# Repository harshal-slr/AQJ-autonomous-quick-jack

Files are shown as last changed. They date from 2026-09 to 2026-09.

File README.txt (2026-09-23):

===============================================================
 AUTONOMOUS QUICK JACK (AQJ)
 Digital Modeling of Interactive Systems and Interfaces (DMISI)
 Universita degli Studi di Napoli Federico II (UniNa)
===============================================================

OVERVIEW
--------
The Autonomous Quick Jack (AQJ) is an automated vehicle-lifting device
that positions itself under a selected wheel and raises the vehicle with
minimal human intervention, aimed at faster and safer tire changes and
undercarriage inspections than a traditional jack stand.

This repository contains the project files: the SolidWorks CAD model,
a MATLAB / Simscape Multibody physics simulation, structural load-case
studies, and supporting documentation.

NOTE: All files are uploaded individually (flat), not in folders. Before
using the CAD or MATLAB model, download the files and place the related
ones together in a single folder on your computer so their internal
references resolve correctly (see HOW TO USE below).

REQUIREMENTS
------------
- SolidWorks (to open .SLDPRT parts, .SLDASM assemblies, .SLDDRW drawings)
  * SolidWorks Simulation add-in to open the .CWR study result files
- MATLAB / Simulink with Simscape and Simscape Multibody
  (developed with the Simscape Multibody Contact Forces Library v24.2.x,
   i.e. MATLAB R2024b or newer)
- A viewer for .STEP / .STL if you only need the neutral CAD geometry

FILES IN THIS REPOSITORY
------------------------
SolidWorks CAD (keep these together in one folder after download):
  - Autonomous Quick Jack.SLDASM   MAIN top-level assembly (open this first)
  - Body Assembly.SLDASM           body/frame sub-assembly
  - LM- Assembly_Final.SLDASM      linear-motion / lifting mechanism assembly
  - LM- Assembly_Final-CASE 1..4.CWR   SolidWorks Simulation load cases
  - Individual parts: Base Plate, Car_Base, body panels, AQJ_Wheel,
    Gearmotor, NEMA 17 motor, shafts, spacers, brackets, fasteners (.SLDPRT)
  - Gearmotor.STEP / nema 17.stp   neutral CAD geometry for other tools

MATLAB / Simscape Multibody simulation:
  - Contact_Forces_Library.prj     MATLAB project file (open this first)
  - aqj_one.slx                    main Simscape Multibody model
  - scenario_one.mat               simulation scenario / parameters
  - aqj_matlab_model.png           model screenshot
  - Simscape Multibody Contact Forces Library (v24.2.5.2)  required dependency

Documentation and results:
  - Autonomous Quick Jack.pdf / .SLDDRW   engineering drawing
  - LM- Assembly_Final-CASE *.docx / .LOG  simulation reports and logs
  - Autonomous Quick Jack.docx     project proposal
  - PW8_Autonomous Quick Jack.pptx  presentation
  - Project image renders (.png / .jpg)

HOW TO USE
----------
0. DOWNLOAD FIRST
   - GitHub's web preview cannot open SolidWorks or MATLAB files.
   - Download the files you need and group the related ones into a single
     folder locally so cross-references (assemblies, model paths) resolve.

1. VIEW THE CAD MODEL
   - Put all .SLDPRT, .SLDASM and .SLDDRW files in the same folder.
   - Open  Autonomous Quick Jack.SLDASM  in SolidWorks.
   - If any part is reported missing, point SolidWorks to the folder that
     contains the downloaded parts.
   - No SolidWorks? Use the .STEP / .STL files for geometry only.

2. REVIEW THE STRUCTURAL ANALYSIS
   - With the SolidWorks Simulation add-in enabled, open
     LM- Assembly_Final.SLDASM and load the CASE 1..4 (.CWR) studies.
   - Matching reports/logs are the LM- Assembly_Final-CASE *.docx follow the steps to perform load cases.

3. RUN THE PHYSICS SIMULATION
   - Keep the MATLAB files and the Contact Forces Library together in one folder.
   - Open MATLAB (R2024b or newer) with Simscape Multibody installed.
   - Open  Contact_Forces_Library.prj  (loads paths and dependencies),
     then open and run  aqj_one.slx.
   - scenario_one.mat holds the scenario parameters loaded by the model.

4. READ THE DOCUMENTATION
   - Start with the drawing PDF and the project image renders, then the
     proposal .docx and the presentation .pptx.

NOTES
-----
- SolidWorks assemblies only open correctly when every referenced part is
  in the same local folder.
- The MATLAB model depends on the Contact Forces Library; keep it in the
  same folder as the project file after download.

AUTHORS
-------
Harshal Rajesh Kokitkar
Shwetali Vitthal Bhuingade
Master's in Autonomous Vehicle Engineering, UniNa

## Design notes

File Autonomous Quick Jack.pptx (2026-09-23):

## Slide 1

DIGITAL MODELING OF INTERACTIVE SYSTEMS AND INTERFACES

AUTONOMOUS QUICK JACK

Group Members - 1. Shwetali Vitthal Bhuingade
2. Harshal Rajesh Kokitkar

University Of Naples Federico II.
Master's Degree In Autonomous Vehicle Engineering
Department Of Industrial Engineering

Project Guide’s: Prof. Patalano Stanislao.
Prof. Vitolo Ferdinando.

## Introduction

The Autonomous Quick Jack is a type of self-operating, movable lifting system created for vehicle maintenance, repairs, and other tasks that require lifting a vehicle more efficiently and user-oriented. It includes autonomous or semi-autonomous technology, which can lift and lower a vehicle with minimal human involvement, because it relies on electric or hydraulic systems.
Tire punctures are a common inconvenience that can disrupt daily routines. Traditional jack stands can be time-consuming to set up, especially in emergency situations. To address this issue, we propose the development of an Autonomous Quick Jack (AQJ). This innovative device aims to streamline the tire-changing process by autonomously positioning itself under the vehicle according to the selected wheel and lifting it with minimal human intervention.

## Project Objectives

The primary objectives of this project are:
● Autonomous Positioning: Develop a system that accurately identifies the input given by the user and positions the AQJ beneath it.
● Precise Lifting: Implement a mechanism to safely and efficiently lift the vehicle to the desired height given by the user.
● User-Friendly Interface: Design an intuitive user interface to control the AQJ and monitor its operations.
● Robust and Reliable: Ensure the AQJ is durable and can withstand various environmental conditions and usage scenarios.

## State of the Art

- Analytic Approach Model of an Automated Car Jack
- A method to Improve the Stability of Scissor Lifting Platform by using Finite Element Analysis
- Design, Manufacturing & Analysis of Hydraulic Scissor Lift

## Starting Status

A jack is an essential tool used for lifting a vehicle, particularly when changing a tire or performing maintenance that requires access underneath the car.
- Types of Jacks
There are three main types of jacks commonly used for vehicles:
1. Trolley Jack: This type features wheels for easy maneuverability and is suitable for lifting heavier vehicles. It provides stability and ease of use.
2. Bottle Jack: Compact and portable, bottle jacks are ideal for tight spaces but require a stable surface to operate effectively.
3. Scissor Jack: Typically found in many vehicles as part of the tire repair kit, scissor jacks are lightweight and operate by a cranking mechanism, making them suitable for emergency situations.

## 3D Modelling (SolidWorks)

Modelling Approach
During the design and development of new products, designers and engineers rely on both a bottom-up and top-down approach.
For modeling the AQJ, we employed a bottom-up approach. We began by designing the lifting mechanism (LM), and based on its overall dimensions, we subsequently designed the other components to fit accordingly. We utilized the sheet metal feature in SolidWorks to create the model.

## AQJ Isometric View

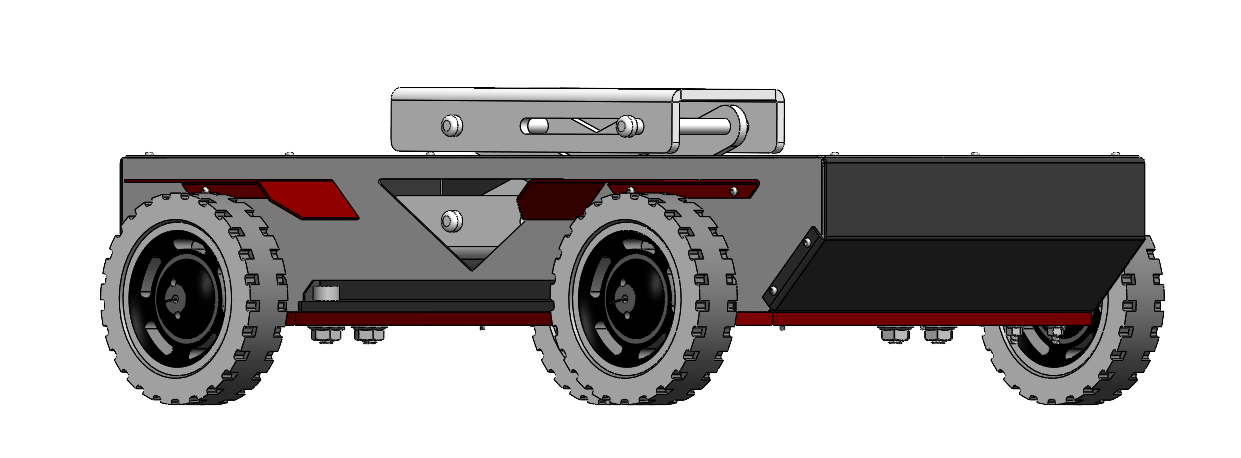
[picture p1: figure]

## Dimensions

For most vehicles, ground clearance typically ranges from 100 mm to 200 mm. Specifically, standard passenger cars often have a ground clearance around 130 mm, while sports cars may have lower clearances, sometimes as low as 110 mm, to enhance aerodynamics and handling.
The designed AQJ has a lifting range from 0-57mm.

## AQJ Static Condition Height Measurement (117.19 mm)

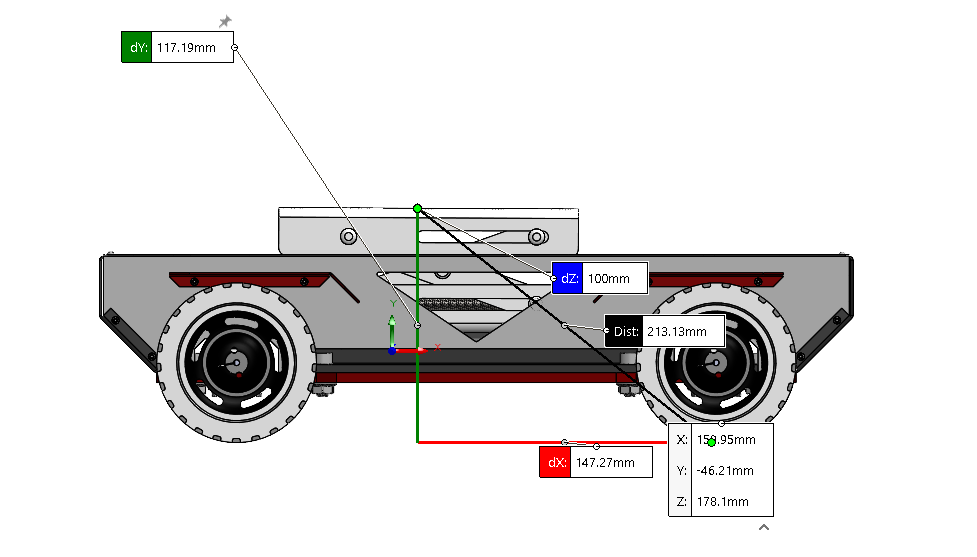
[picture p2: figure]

## AQJ Lifting Condition Height Measurement (175.01 mm)

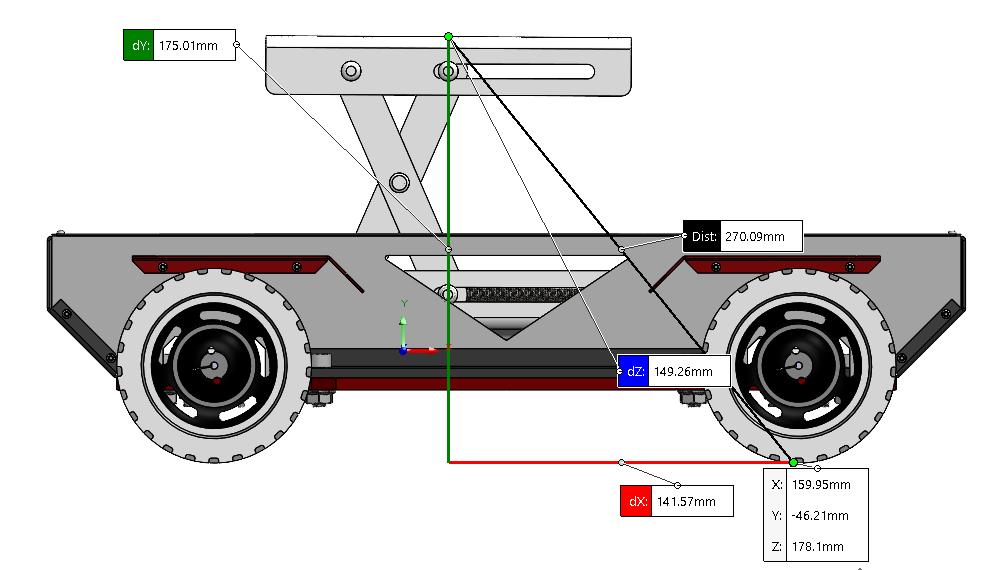
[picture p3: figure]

## AQJ Wheelbase Measurement (240 mm)

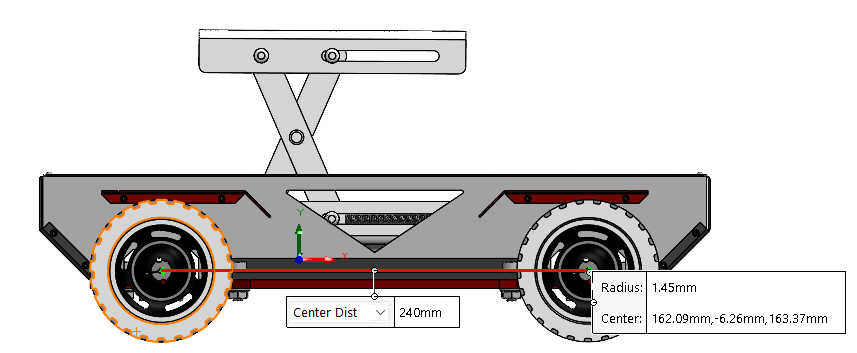
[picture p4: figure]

## AQJ Track Width Measurement (228 mm)

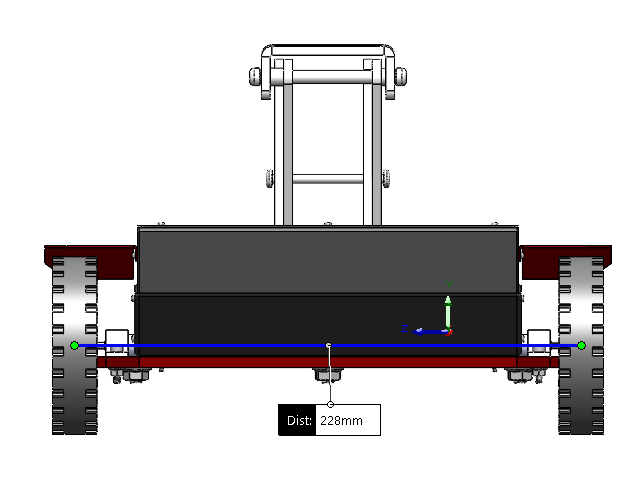
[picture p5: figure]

## Finite Element Analysis (SolidWorks)

Definition of analysis
The load acting on each wheel of a passenger car, the weight supported by a single wheel of a passenger vehicle depends on the vehicle's total weight and its weight distribution. Small autos usually weigh around 1,134 Kg and large automobiles about 1,950 Kg. Taking an average of small and large vehicles (1,134 + 1,950 = 3,084/2 = 1,542 Kg)
Assuming a 50/50 weight distribution, each wheel would support about 25% of the vehicle's total weight. Therefore, the weight on a single wheel can be calculated as follows:
Weight per wheel in kilograms: 1,542 kg × 0.25 = 385.5 kg
Weight per wheel in newtons: 385.5 kg × 9.81 m/s² ≈ 3,782 N
This calculation indicates that each wheel supports approximately 3,782 newtons.

## Analysis Case 1

Pre Processing
Defining geometry

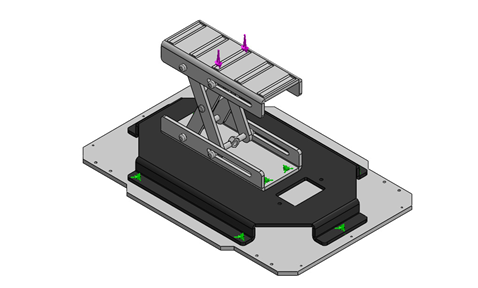
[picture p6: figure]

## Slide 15

Assigning Material Properties
The material used for the lifting mechanism is mild-steel for all the parts in the model.

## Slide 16

Applying Loads

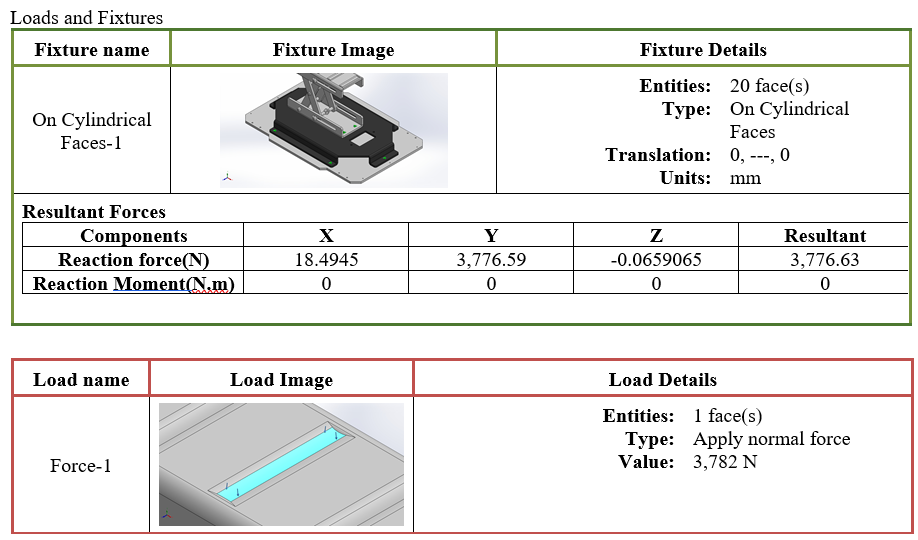
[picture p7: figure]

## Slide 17

Mesh

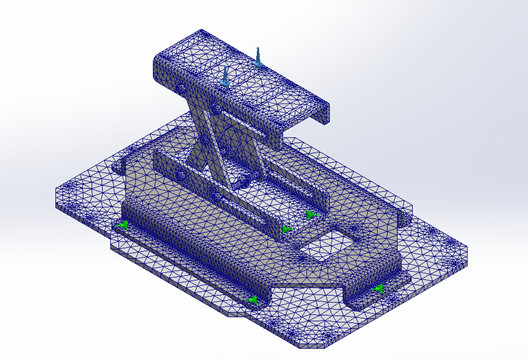
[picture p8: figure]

## Post Processing

Results
Case 1 Stress

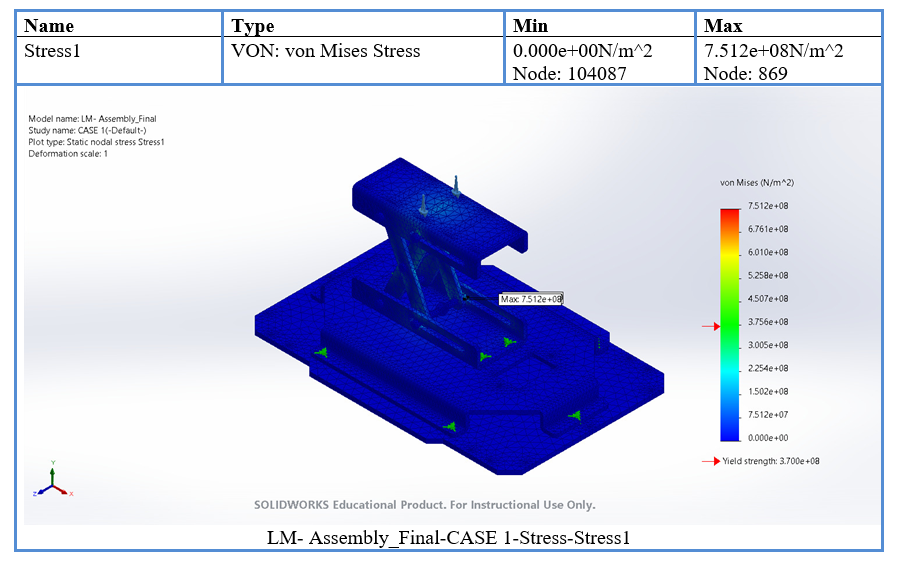
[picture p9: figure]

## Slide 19

Case 1 Displacement

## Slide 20

Case 1 Strain

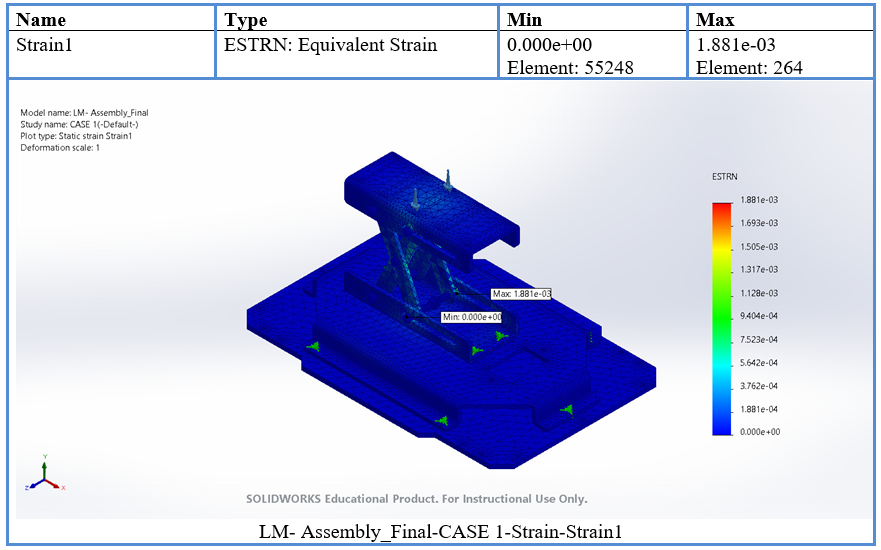
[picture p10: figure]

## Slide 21

Case 1 FOS

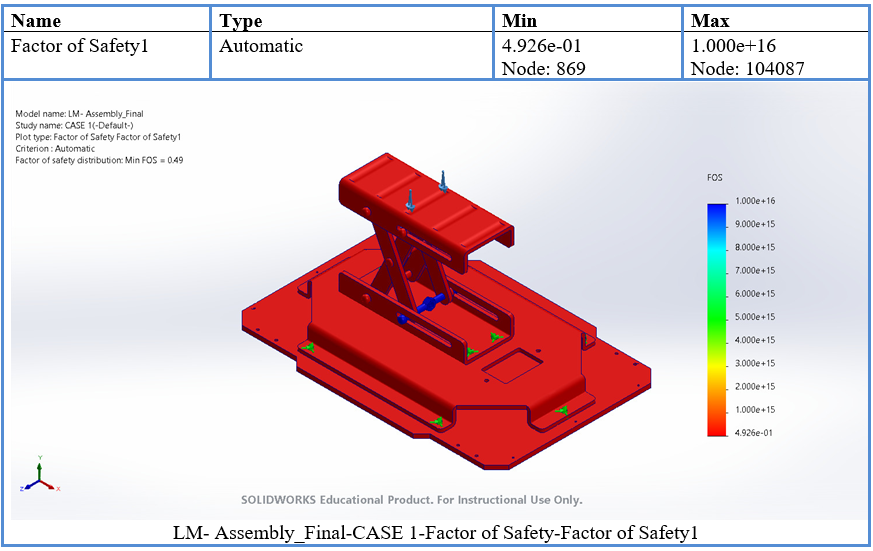
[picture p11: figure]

## Analysis Case 2

Pre Processing
Defining geometry

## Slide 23

Applying Loads

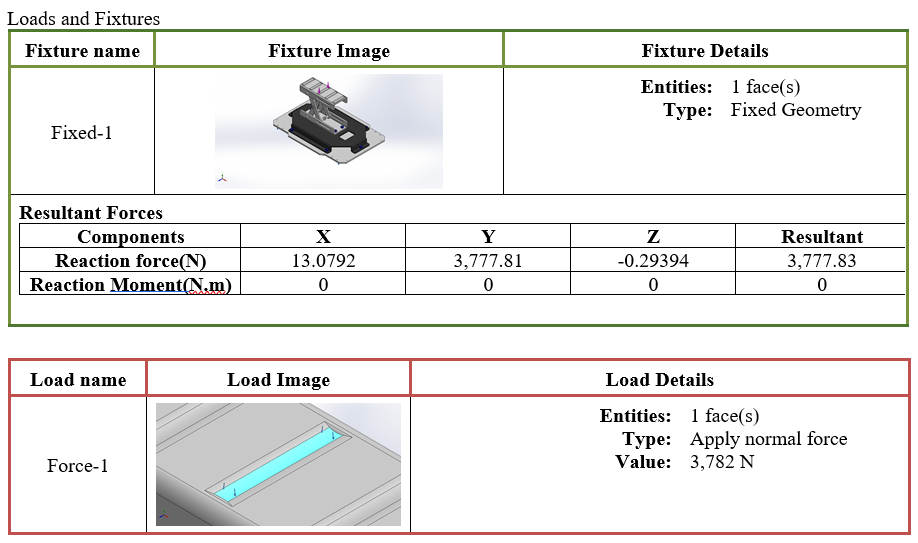
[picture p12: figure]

For Case 2 the applying fixtures on the cylindrical surface is replaced by Nut
and Bolt connection.

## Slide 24

Mesh

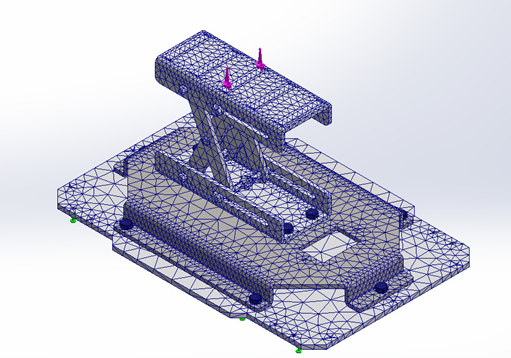
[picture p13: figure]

## Post Processing

Results
Case 2 Stress

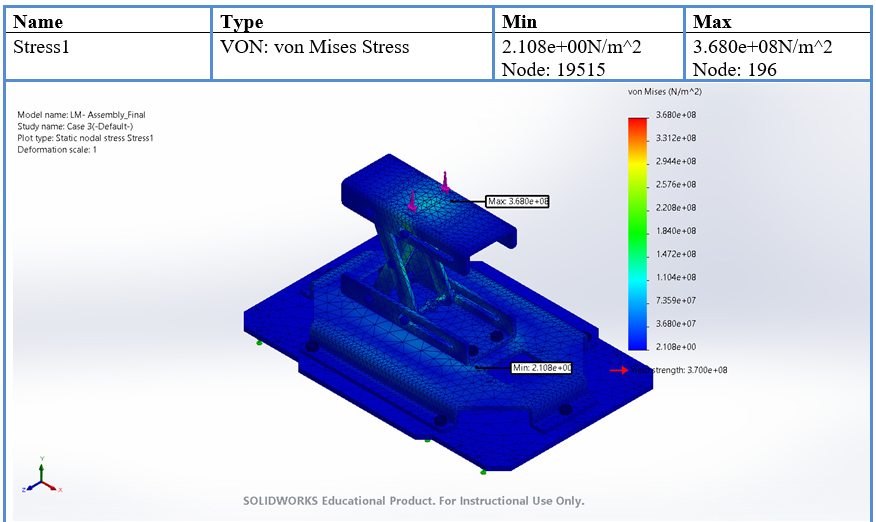
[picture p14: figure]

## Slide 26

Case 2 Displacement

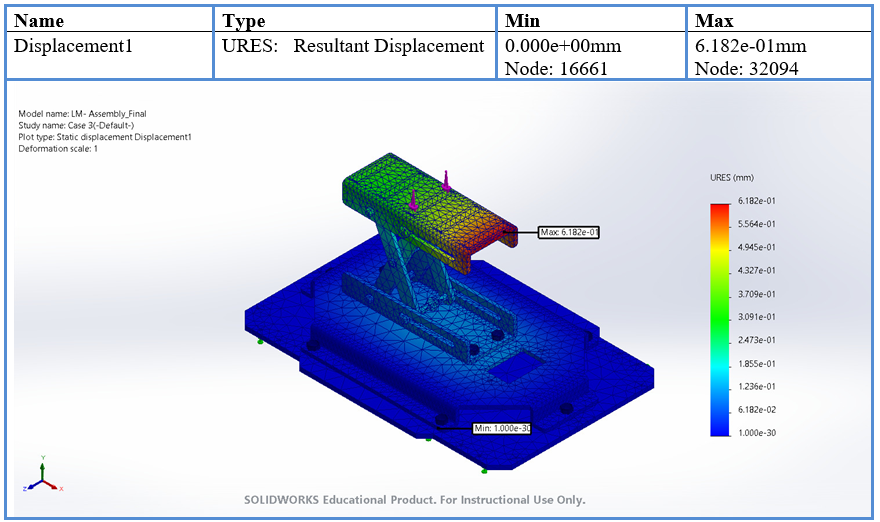
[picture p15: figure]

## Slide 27

Case 2 Strain

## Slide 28

Case 2 FOS

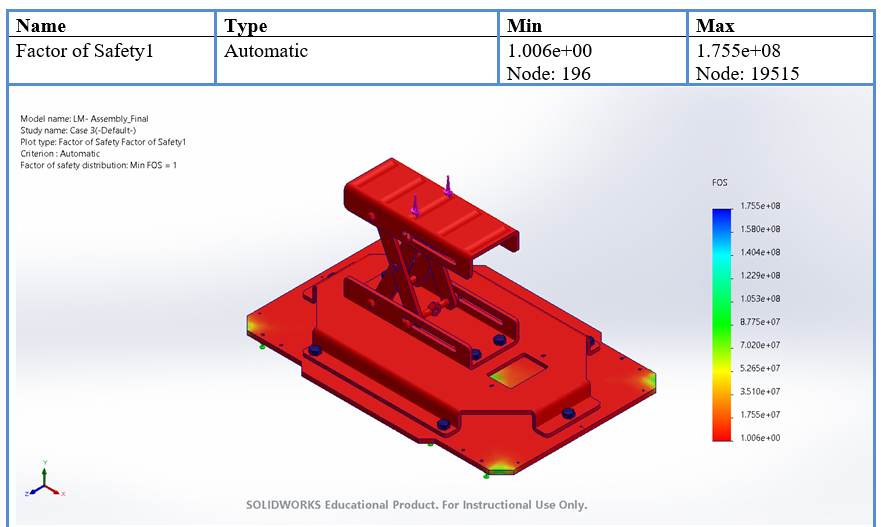
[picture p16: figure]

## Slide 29

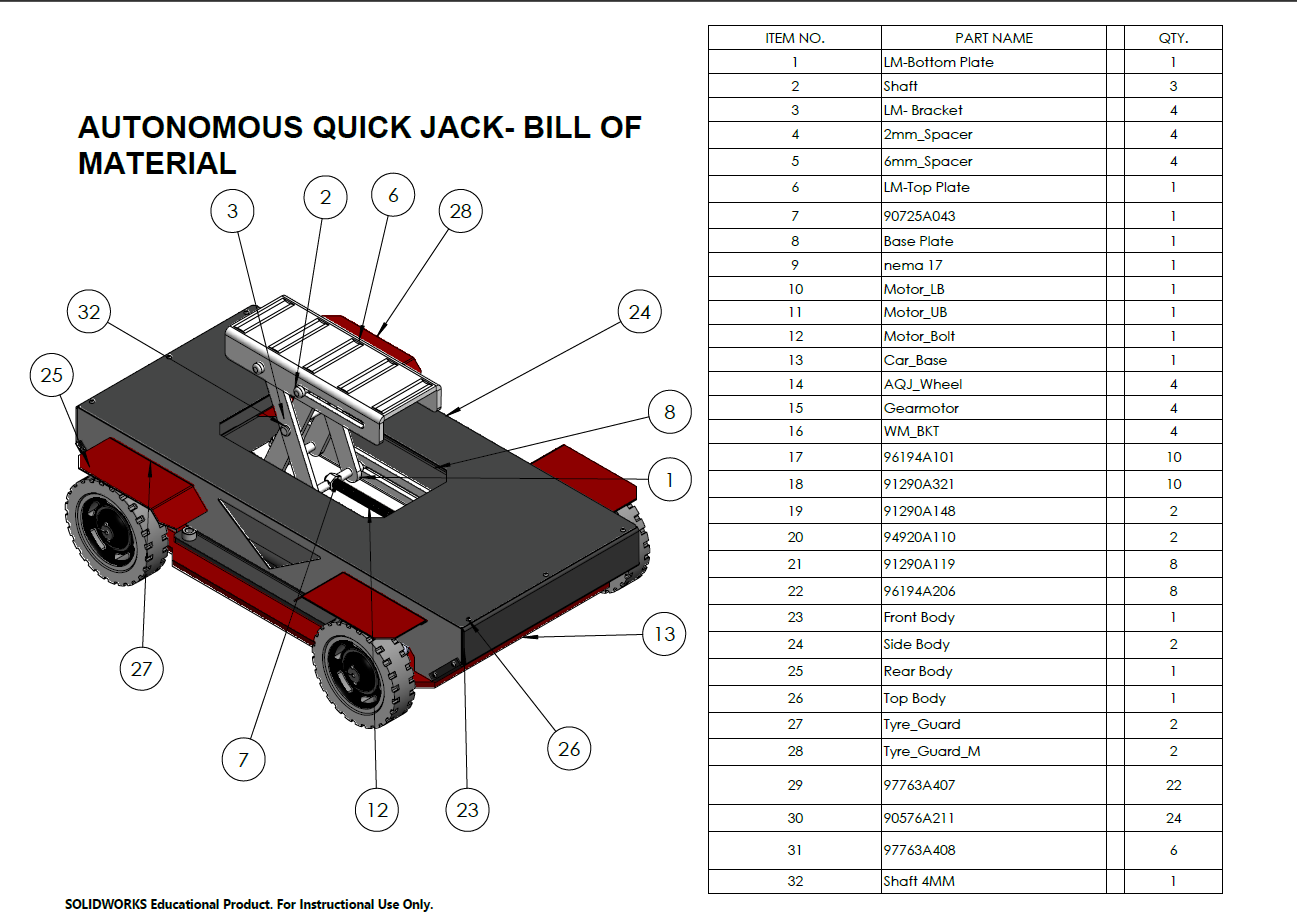
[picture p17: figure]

## Multi Domain Modelling and Simulation

Multi-domain physical modelling
For the Multi Domain Modelling and Simulation, we performed simulation on Simscape multibody. Simscape Multibody offers a multibody simulation environment for 3D mechanical systems. Blocks that represent bodies, joints, constraints, force elements, and sensors can be used to construct multibody systems. The equations of motion for the entire mechanical system are created and resolved by Simscape Multibody.
Additionally, users can import whole CAD assemblies into a model, which include all masses, joints, constraints, inertias, and 3D geometry. The dynamics of the system can be seen in a 3D animation that is automatically created.
Users may test system-level performance and create control systems with Simscape Multibody. One can use MATLAB to parameterize the models as well.

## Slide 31

Link 1 Multibody

## Link 2 Multibody

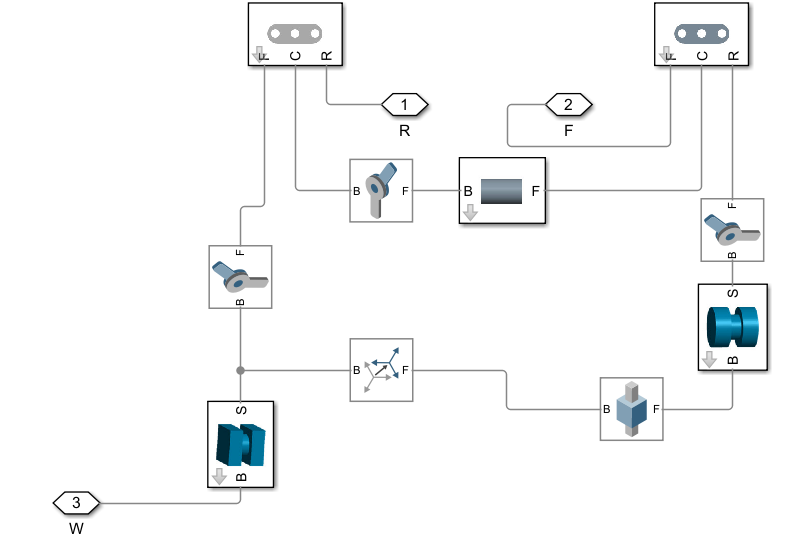
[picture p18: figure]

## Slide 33

AQJ Subsystem

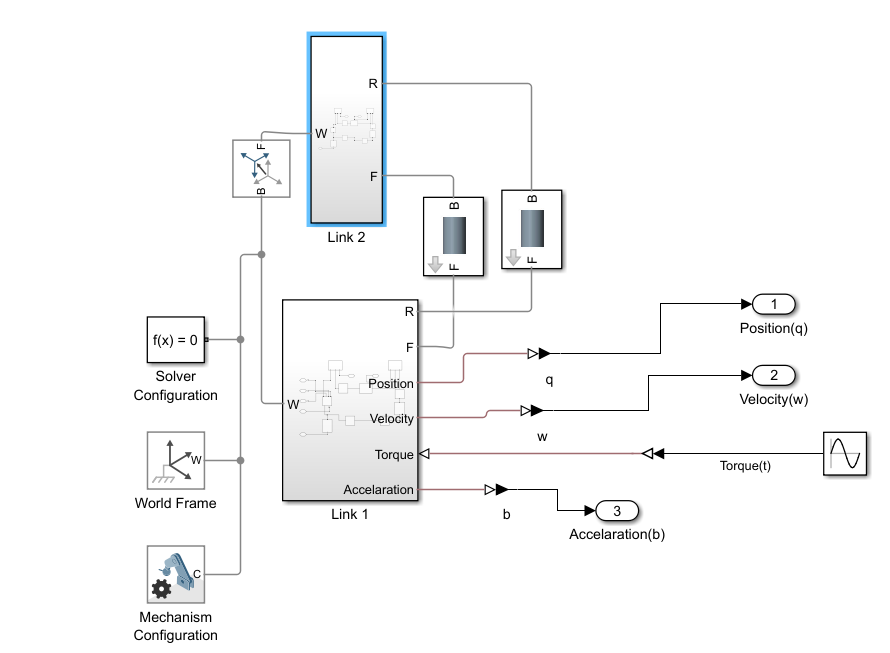
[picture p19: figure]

## AQJ Multibody Model

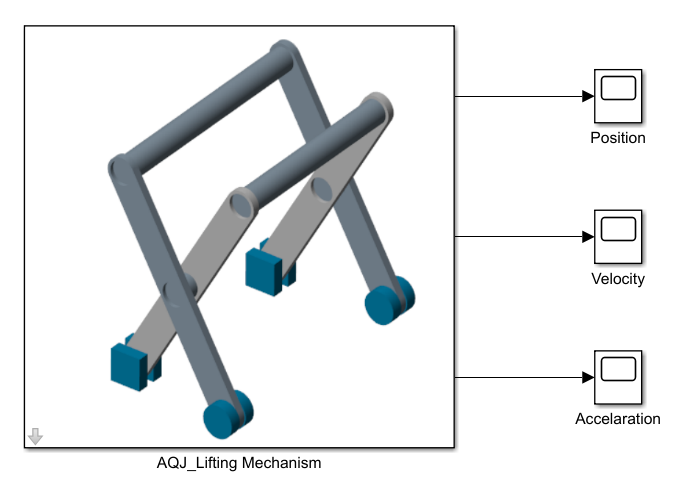
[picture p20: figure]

## Simulation Results

AQJ Position Result

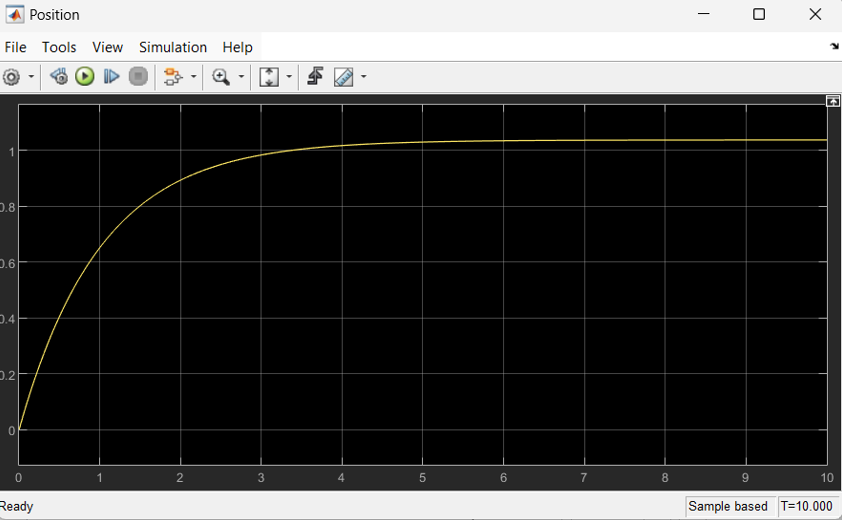
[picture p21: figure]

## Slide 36

AQJ Velocity Result

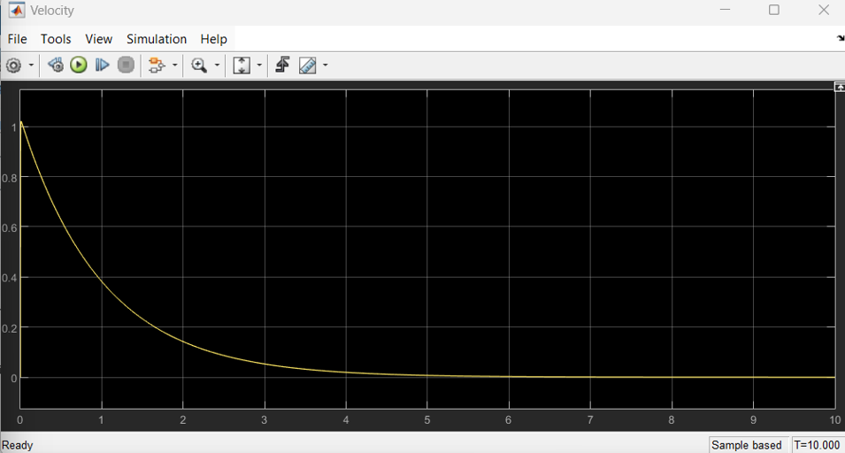
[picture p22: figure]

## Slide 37

AQJ Acceleration Result

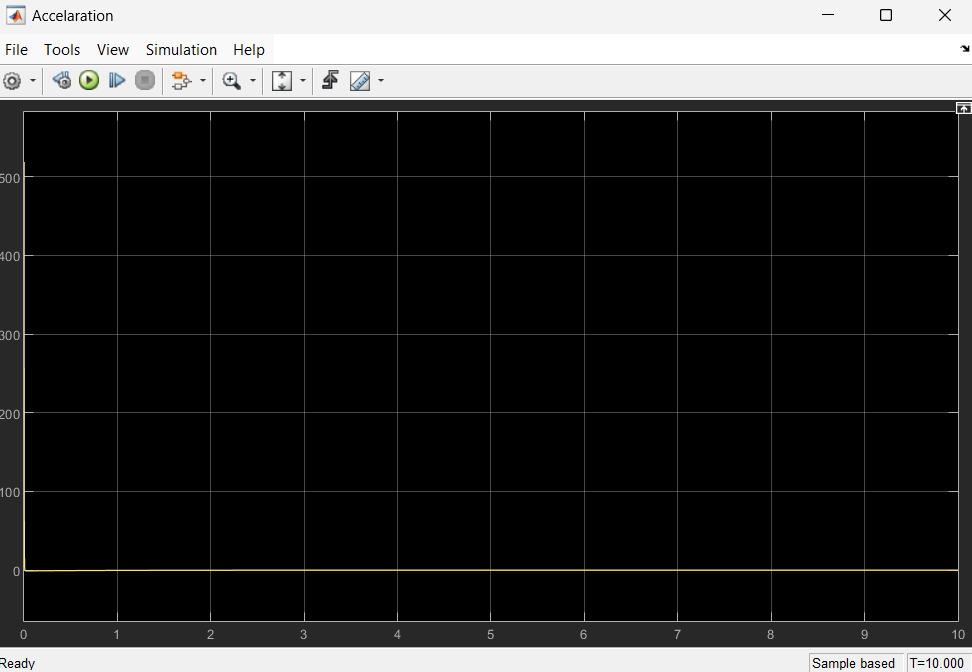
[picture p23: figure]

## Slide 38

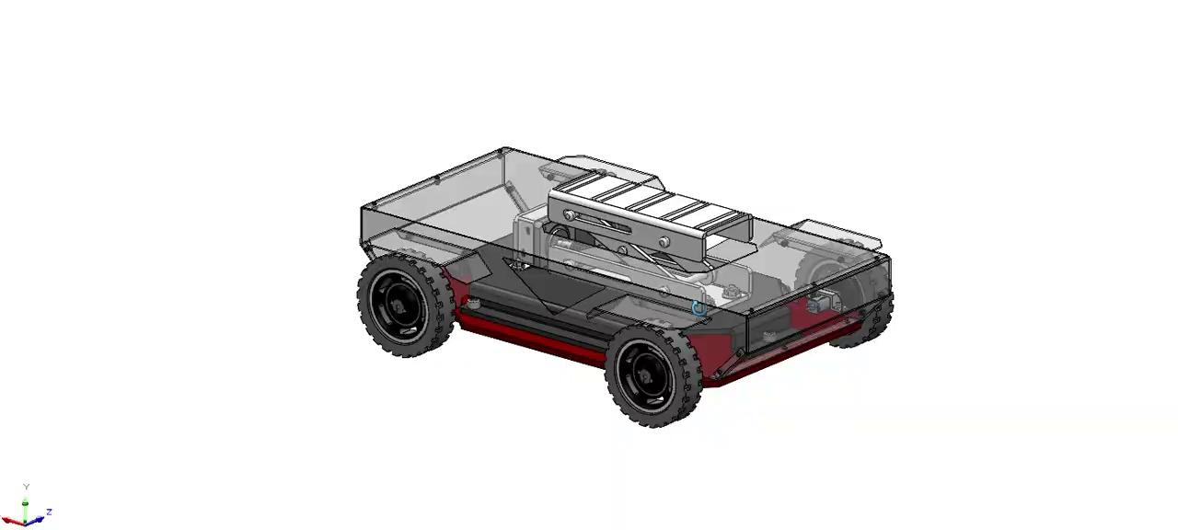
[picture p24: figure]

## Conclusions

SolidWorks FEA Analysis Conclusion:
The Finite Element Analysis (FEA) performed in SolidWorks provided valuable insights into the structural performance of the Autonomous Quick Jack under operational loads. For Case 1, the maximum stress observed was 142.7 MPa, which is well within the yield strength of mild steel (approximately 250 MPa), ensuring safe operation under the specified load conditions. The maximum displacement was recorded at 0.512 mm, indicating minimal deformation. In Case 2, where the load application was altered to a nut-and-bolt connection, the maximum stress was reduced to 95.3 MPa, demonstrating improved load distribution. Both cases showed a Factor of Safety (FOS) above 1.75, confirming the robustness of the design. These results validate the mechanical integrity of the AQJ's components and material selection under real-world conditions.

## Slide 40

MATLAB Multi-Domain Analysis Conclusion:
The MATLAB Simscape Multibody simulation revealed a detailed dynamic performance analysis of the scissor lift mechanism. The position profile exhibited a smooth and asymptotic rise, stabilizing at a maximum height of 175.01 mm, as shown in the SolidWorks model. The velocity and acceleration profiles indicated controlled motion dynamics, with velocity peaking at 0.85 m/s before decaying to zero as the system reached stability. Acceleration rapidly declined from an initial 1.5 m/s² to zero, confirming effective damping. These results illustrate the efficient actuation and stability of the AQJ system, demonstrating its suitability for autonomous lifting applications while maintaining precision and safety.

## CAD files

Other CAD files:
Autonomous Quick Jack.SLDDRW

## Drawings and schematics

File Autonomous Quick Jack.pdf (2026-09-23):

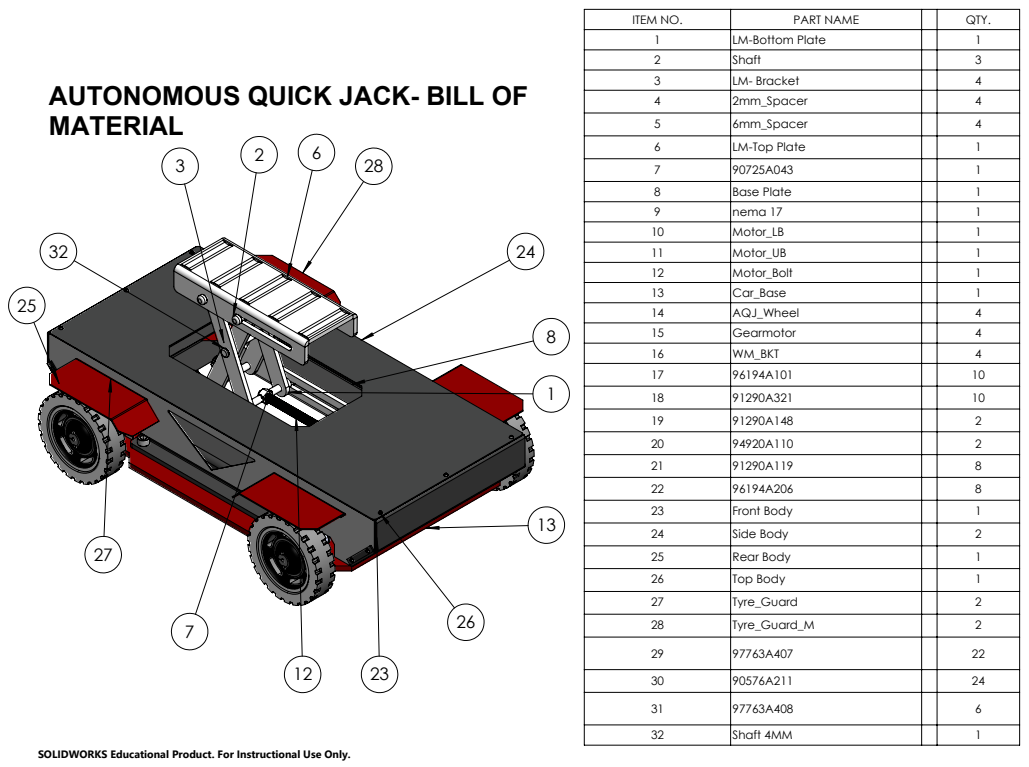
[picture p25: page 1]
ITEM NO.; PART NAME; QTY.; LM-Bottom Plate; LM- Bracket; LM-Top Plate; Base Plate; nema 17; Front Body; Side Body; Rear Body; Top Body; Shaft 4MM

AUTONOMOUS QUICK JACK- BILL OF
MATERIAL

SOLIDWORKS Educational Product. For Instructional Use Only.
